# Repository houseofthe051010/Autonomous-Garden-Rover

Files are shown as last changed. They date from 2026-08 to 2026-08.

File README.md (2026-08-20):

# Autonomous Garden Rover

This is an open source outdoor garden robot that can mow grass and water plants for under $400. It features a powerful 3000 watt C6374 motor for mowing grass with electronic height control, and a large Nema17 turret system for watering at target places that supports a normal garden hose. The rover currently uses a 9 axis IMU + wheel encoders for autonomous function. The brain of this rover is a powerful ESP32-P4, which gives this rover the capability to listen and respond to commands using its built in microphone and speaker. 

## Inspiration

I spend hours each week gardening and mowing grass. As someone into robotics, I realized I could build a garden rover to automate some of these repetitive chores. This project gave me a reason to learn more about robotics while building something useful for my yard.

[**Watch the demo**](https://youtu.be/P-olpegfmmU) · [**Macondo journal**](https://macondo.hackclub.com/projects/9276) · [**See the assembly**](CAD/)

Autonomous Garden Rover demo (https://youtu.be/P-olpegfmmU)

## Features

* Under $400, anyone can build it
* All four wheels are motorized
* C6374 Motor offers 3000W+ of power, more than most commercial systems
* Nema17 planetary motors lift and raise the mower using a rope system.
* The turret system uses high reduction worm + dual stage planetary drives to shoot water
* Has a microphone and speaker and can run small ai vision/text recognition models
* Water flow can be controlled using a seperate esp32 controller
* Can be controlled from a phone or handheld controller
* Uses a 9axis imu and encoders on all four wheels for precise autonomous
* The aluminum chassis bends and acts as a suspension
* Supports raspberry pi 5 with ROS 2 as brain
* Supports a custom hand held controller from my previous FPV claw drone project
* Advanced flexibility for conneting new sensors, cameras, and electronics
* Water resistant

# Building it yourself

Go to [**INSTRUCTIONS.md**](INSTRUCTIONS.md) to see the complete build instructions.

## Block schematic

This is a block level schematic of how each system is split

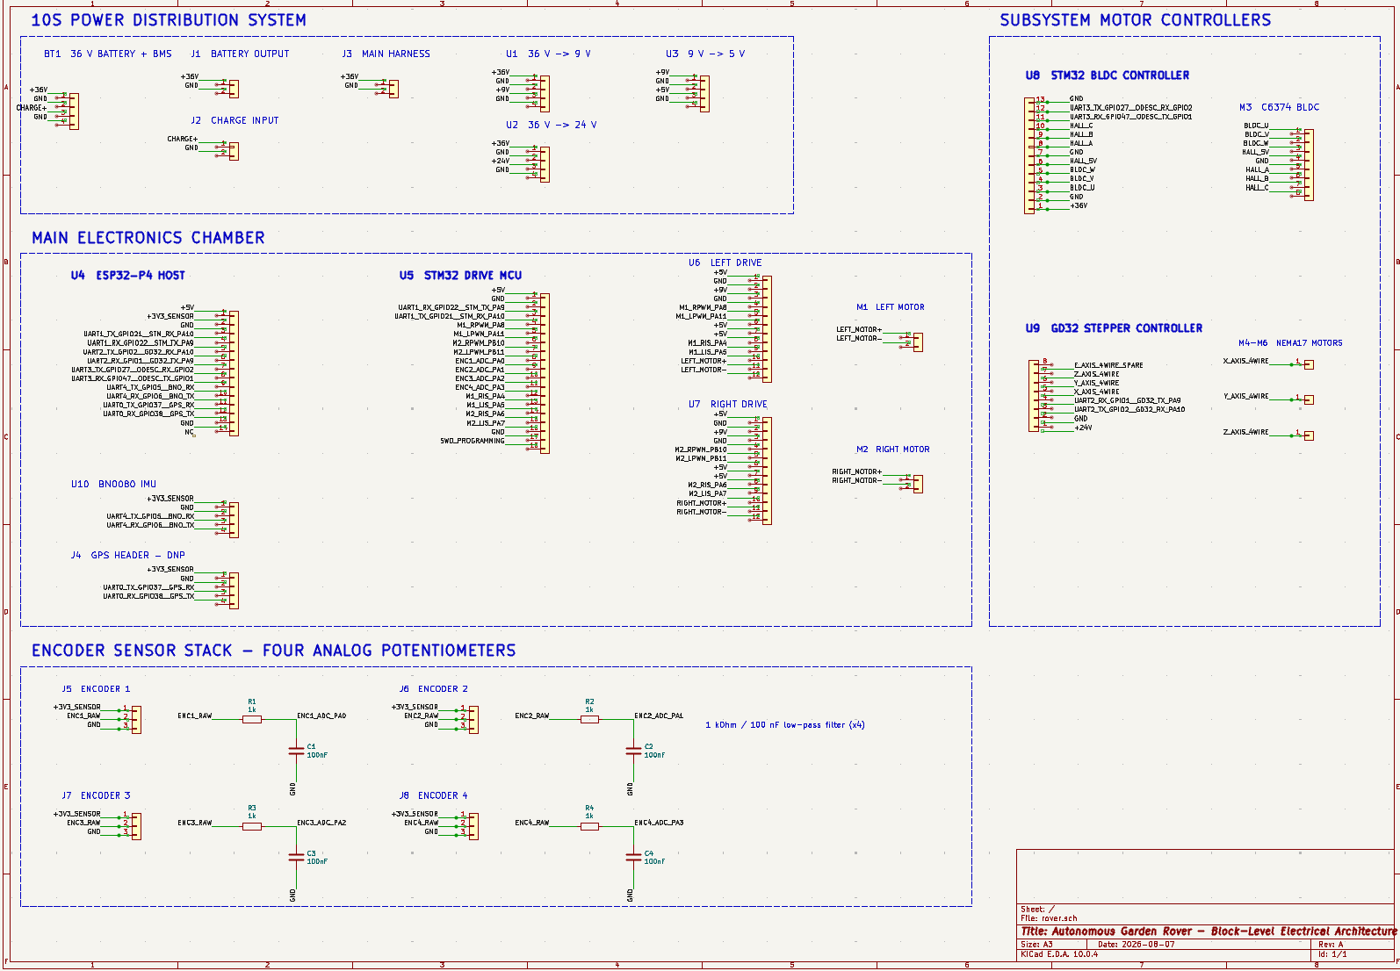
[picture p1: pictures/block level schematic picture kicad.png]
Block-level electrical schematic


Kicad: [`Schematics/Block-level schematic/`](Schematics/Block-level%20schematic/).

## Bill of materials

| Item | Qty. | Unit price | Total | Link |
| --- | ---: | ---: | ---: | --- |
| Waveshare ESP32-P4-WIFI6 development board | 1 | $26.87 | $26.87 | [Amazon](https://www.amazon.com/dp/B0FM3SPXZG) |
| Steelworks 3/4 in x 8 ft aluminum channel | 2 | $19.98 | $39.96 | [Lowe's](https://www.lowes.com/pd/Steelworks-3-4-in-W-x-8-ft-L-Mill-Finished-Aluminum-Weldable-Trim-Channel/3058185) |
| LGXSHOP C6374 170KV sensored BLDC motor | 1 | $29.50 | $29.50 | [Amazon](https://www.amazon.com/dp/B0GR88K1XP) |
| STM32F103C6T6 Blue Pill development board | 1 | $1.75 | $1.75 | [AliExpress](https://www.aliexpress.us/item/3256809531654480.html) |
| BTS7960 high-current motor driver board | 2 | $5.56 | $11.12 | [AliExpress](https://www.aliexpress.us/item/3256812145540065.html) |
| DS3230 PRO drivetrain servo motors (4-pack) | 1 | $41.37 | $41.37 | [AliExpress](https://www.aliexpress.us/item/3256808314550897.html) |
| STEPPERONLINE NEMA 17 stepper motors (3-pack) | 1 | $25.99 | $25.99 | [Amazon](https://www.amazon.com/dp/B0B38GHRH8) |
| Stepper controller board (12-24 VDC) | 1 | $22.99 | $22.99 | [Amazon](https://www.amazon.com/dp/B0CCVSMGXR) |
| EONO PETG 3D printer filament 1 kg black | 2 | $9.99 | $19.98 | [Amazon](https://www.amazon.com/EONO3D-Printer-Filament-1-75mm-2-2lbs/dp/B0G2BQQ5RT) |
| 608 sealed steel bearings (20-pack) | 1 | $4.99 | $4.99 | [Amazon](https://www.amazon.com/dp/B0GX14YCFF) |
| M3 screw kit (420-piece) | 1 | $8.98 | $8.98 | [Amazon](https://www.amazon.com/dp/B0CSWD34KJ) |
| Flipsky ODESC 56 V v4.2 single-axis controller | 1 | $39.99 | $39.99 | [Amazon](https://www.amazon.com/dp/B0CB64MVHC) |
| 22 AWG wire (10 m) | 1 | $2.81 | $2.81 | [AliExpress](https://www.aliexpress.us/item/3256801511977665.html) |
| 36 V 10.4 Ah lithium battery with charger and XT60 connector | 1 | $79.99 | $79.99 | [eBay](https://www.ebay.com/itm/318206384216) |
| 20 A buck converter | 2 | $3.58 | $7.16 | [AliExpress](https://www.aliexpress.us/item/3256808333733098.html) |
| XL4005 buck converter | 1 | $1.99 | $1.99 | [AliExpress](https://www.aliexpress.us/item/3256808679872256.html) |
| MG996 servo motor | 1 | $3.44 | $3.44 | [AliExpress](https://www.aliexpress.us/item/3256802804659030.html) |
| ESP32-WROOM-32 development board with U.FL | 1 | $7.32 | $7.32 | [AliExpress](https://www.aliexpress.us/item/3256807142919728.html) |
| BNO080/BNO085 9-DOF sensor module | 1 | $18.99 | $18.99 | [Amazon](https://www.amazon.com/dp/B0HCBRBZ76) |
| Hello Hobby 3/8 in x 36 in wood dowel | 1 | $0.78 | $0.78 | [Walmart](https://www.walmart.com/ip/684374236) |
| Tool Bench 40 ft diamond-braid rope with winder | 1 | $1.50 | $1.50 | [Dollar Tree](https://www.dollartree.com/tool-bench-40-ft-diamond-braid-rope-with-winder-1-ct/295406) |
| **Estimated total** | | | **$397.47** | |

## What I would do differently next time and plan for in the future

- Add cameras and GPS+RTK to the autonomous sensors
- Use stronger drivetrain motors to support a higher speed and better turning (though it would increase the price to build)
- Replace garden hose adapter system with a water tank onboard the rover
- Make a custom PCB that combines all the electronics and sub systems into one board with quick connectors for peripherals (much more expensive though)

## Repository Structure

In this repo, I have included everything needed to replicate and modify this project

- Firmware images and source code
- CAD source, assemblies, steps, and STLs
- Visual instruction manual
- Electrical schematics

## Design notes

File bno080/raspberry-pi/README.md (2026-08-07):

# Raspberry Pi 5 BNO080 UART-SHTP Client

This client reads fused and raw BNO080 data through Pi 5 UART4. It is normal
Python 3 code for Raspberry Pi OS and Thonny, not MicroPython.

The UART-SHTP round trip and fused sensor-report path were hardware-validated on
2026-07-22. See [`VALIDATED_WORKING_MODEL.md`](VALIDATED_WORKING_MODEL.md) for
the observed output, exact wiring, and remaining calibration work.

## Wiring

| Raspberry Pi 5 | Physical pin | BNO080 |
| --- | ---: | --- |
| GPIO12 / UART4 TX | 32 | RX, sometimes labelled SCL/RX |
| GPIO13 / UART4 RX | 33 | TX, sometimes labelled SDA/TX |
| GPIO22 | 15 | H_INTN, optional but recommended |
| GPIO23 | 16 | NRST, optional for the first test |
| GND | Any GND | GND |

UART signals are 3.3 V. Set UART-SHTP mode before sensor reset or power-up:

```text
PS1 = HIGH
PS0 = LOW
```

Breakout-board power inputs differ. Do not connect its power pin until the exact
module documentation confirms whether the pin expects regulated 3.3 V or a
higher `VIN`. A bare BNO080 uses 3.3 V-class power and logic.

## Enable UART4

Under `[all]` in `/boot/firmware/config.txt`:

```ini
dtoverlay=uart4-pi5
```

Save, reboot, and verify:

```sh
ls -l /dev/ttyAMA4
pinctrl get 12-13
```

Expected pin functions are UART4 TX on GPIO12 and UART4 RX on GPIO13.

## Python dependency

The client is standalone except for `pyserial`, which is already used by the
working STM32 client. Install it from Raspberry Pi OS if needed:

```sh
sudo apt update
sudo apt install python3-serial
```

In Thonny, use the same regular Python 3 interpreter as the validated STM32
motor client. Paste or open and run [`bno080_uart.py`](bno080_uart.py). No
virtual environment, Adafruit package, `board`, or `busio` module is required.

## Connection result

Before initializing sensor reports, the program performs an SHTP Buffer Status
Query/Notification round trip. A correct connection prints:

```text
BNO080 UART opened: /dev/ttyAMA4 at 3000000 baud (Pi TX GPIO12, RX GPIO13)
BNO080 UART-SHTP ROUND TRIP VERIFIED: buffer=... bytes
BNO080 SHTP reset complete
BNO080 initialized; fused navigation reports received
BNO080 dynamic accel/gyro/magnetometer calibration started
```

The executable-channel reset makes repeated Thonny runs reliable while the
BNO080 remains powered. Without it, the host's channel sequence counters restart
at zero but the sensor can retain its previous SHTP state and ignore new Set
Feature commands even though Buffer Status Query still responds.

If this round trip fails, check crossed TX/RX, common ground, UART-SHTP mode,
sensor power, and `/dev/ttyAMA4`. Do not randomly change the baud rate:
UART-SHTP is fixed at 3,000,000 baud, 8N1.

## Thonny shell

Print one fused sample:

```python
print_sample()
```

Read only the calibrated magnetometer vector `(x, y, z)` in microtesla:

```python
magnetometer()
print_magnetometer()
stream_magnetometer(5, 10)
```

The last command prints magnetometer, fused magnetic heading, and accuracy at
5 Hz for ten seconds. Use `stream_magnetometer(5)` to continue until Ctrl+C.

Print fused heading and vectors at 5 Hz for ten seconds:

```python
stream(5, 10)
```

Stream until Ctrl+C:

```python
stream(5)
```

Enable and display raw sensor ADC values for calibration logging:

```python
enable_raw_reports()
print_raw()
stream_raw(5, 10)
```

Check the accuracy field from the calibrated magnetometer report:

```python
calibration_status()
```

The client starts dynamic calibration automatically. With the sensor mounted in
its intended orientation and the drive motors stopped, slowly rotate the robot
or sensor through multiple headings and tilt it through different orientations.
Repeat until `calibration_status()` reaches `2` or preferably `3`. Keep the
sensor away from steel, magnets, motor power cables, speakers, and high-current
wiring while calibrating. Call `begin_calibration()` to restart the process.

An accuracy value of `0` is the sensor's own `unreliable` status, not a Python
placeholder. It is normal before calibration, but persistent zero can indicate
strong magnetic interference or insufficient movement through different axes.

This standalone subset does not write calibration records. That is intentional
for the first hardware test; it avoids changing persistent sensor state.

## Data provided

- Magnetic-north heading derived from the 9-axis rotation-vector quaternion.
- Rotation-vector quaternion `(i, j, k, real)`.
- Calibrated magnetic field in microtesla.
- Calibrated gyro in radians per second.
- Acceleration and gravity-removed linear acceleration in m/s^2.
- Optional raw accelerometer, gyroscope, and magnetometer ADC values.

The embedded driver implements the framing, buffer handshake, Set Feature
commands, and selected report formats from CEVA's binary
[UART-SHTP protocol](https://www.ceva-ip.com/wp-content/uploads/Sensor-Hub-Transport-Protocol.pdf)
and [SH-2 reference](https://www.ceva-ip.com/wp-content/uploads/SH-2-Reference-Manual.pdf).

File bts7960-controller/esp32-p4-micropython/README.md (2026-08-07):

# ESP32-P4 MicroPython STM32 UART Test

[`main.py`](main.py) is a standalone Thonny client for checking the existing
STM32F103 dual-BTS7960 firmware from an ESP32-P4.

## Wiring

The script tests both possible orientations automatically:

| Preferred connection | Direction |
| --- | --- |
| ESP32-P4 GPIO22 | TX to STM32 PA10 / USART1 RX |
| ESP32-P4 GPIO21 | RX from STM32 PA9 / USART1 TX |
| ESP32-P4 GND | STM32 GND |

If GPIO21 and GPIO22 are reversed, the script detects the STM32 heartbeat and
reconfigures UART1 to the reversed orientation. Both devices use 3.3 V UART
logic at 115200 baud, 8N1.

## Thonny

Use a current ESP32-P4 MicroPython build. Save the complete script to the
ESP32-P4 as `main.py`, then reset the board. A working link prints:

```text
received HB ...
UART round trip verified: OK PONG
STM32 CONNECTED: ...
```

Useful shell commands:

```python
ping()
check_connection()
motor_status()
currents()
monitor(5)
diagnostics()
stop_all()
```

`ping()` must return `OK PONG`. A heartbeat alone verifies only the
STM32-to-ESP32 direction; the PING/PONG exchange verifies both directions.
No background thread is started, so the Thonny shell remains usable.

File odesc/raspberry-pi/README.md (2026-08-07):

# Raspberry Pi 5 ODESC UART Client

This directory contains the regular Python 3/Thonny client for the rover's
ODESC (ODrive v3-compatible) motor controller. The bidirectional UART link was
hardware-validated on 2026-07-22. See
[`VALIDATED_WORKING_MODEL.md`](VALIDATED_WORKING_MODEL.md) for the observed
results.

## Wiring

| Raspberry Pi 5 | Physical pin | ODESC | Direction |
| --- | ---: | --- | --- |
| GPIO4 / UART2 TX | 7 | GPIO2 / UART RX | Pi to ODESC |
| GPIO5 / UART2 RX | 29 | GPIO1 / UART TX | ODESC to Pi |
| GND | Any Pi GND | GND | Common reference |

TX and RX must cross. Both devices use 3.3 V UART logic; do not put 5 V on a
UART signal. Power the ODESC from its intended motor power supply and connect
the grounds.

## Raspberry Pi setup

Add this under `[all]` in `/boot/firmware/config.txt`:

```ini
dtoverlay=uart2-pi5
```

Reboot, then verify:

```sh
ls -l /dev/ttyAMA2
pinctrl get 4-5
```

Install the only Python dependency:

```sh
sudo apt update
sudo apt install python3-serial
```

## Run the test

Open [`odesc_uart.py`](odesc_uart.py) in Thonny using its regular local Python 3
interpreter and run it. A successful result includes:

```text
ODESC UART ROUND TRIP VERIFIED
Bus voltage: 35.653049 V
UART enabled=1 baud=115200 | axis1 state=1 error=0
```

The voltage is only an example from the validation run and will follow the
connected motor supply. State `1` means idle. The firmware sometimes formats a
zero integer as `0d`; the client handles that representation.

## Robot API use

The client can be imported without performing I/O automatically:

```python
from odesc_uart import ODESCUART

odesc = ODESCUART()
odesc.open()
status = odesc.check_connection()
voltage = odesc.read_float("vbus_voltage")
odesc.close()
```

`query()` serializes access with a lock, validates one-line commands, and
applies a bounded timeout. The combined rover service keeps one `ODESCUART`
instance open so no other process may own `/dev/ttyAMA2`.

The client now provides:

- `telemetry()` for `vbus_voltage`, `ibus`, bus watts, and both axis snapshots.
- Per-axis position, velocity, measured/setpoint Iq, limits, calibration flags,
  state, component errors, sensorless-estimator velocity/error, motor pole
  pairs, flux linkage, and startup-ramp values.
- `configure_velocity_axis()` for volatile velocity mode and current/speed
  limits.
- `configure_sensorless_axis()` for legacy state-5 ramp settings expressed as
  mechanical turns/s and converted to electrical radians/s internally.
- `start_sensorless()`, `set_sensorless_velocity()`, and `stop_sensorless()`,
  including minimum-speed, fixed-direction, and IDLE-stop enforcement.
- `calibrate_motor()` for an encoderless axis that needs motor-only calibration.
- `clear_errors()` and guarded `calibrate_axis()`.
- Closed-loop state requests and signed velocity commands through the combined
  rover controller.

The deployed dashboard adds an 800 ms host-process velocity deadman, explicit
arm/calibration phrases, and persistent command/error records in
`~/rover-controller/rover-history.sqlite3`. Motor motion from the sensorless
controls has not yet been physically validated. The deadman cannot protect
against Pi power loss or every process failure; use an independent hardware
emergency stop.

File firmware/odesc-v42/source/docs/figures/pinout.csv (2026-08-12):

# | Label | GPIO_MODE_DIGITAL | GPIO_MODE_ANALOG_IN | GPIO_MODE_UART_A | GPIO_MODE_UART_B | GPIO_MODE_PWM | GPIO_MODE_CAN_A | GPIO_MODE_I2C_A | GPIO_MODE_ENC0 | GPIO_MODE_ENC1 | GPIO_MODE_MECH_BRAKE
0 | not a pin
1 | GPIO1 (+) | general purpose | analog input | **UART_A.TX** |  | PWM0.0 |  |  |  |  | mechanical brake
2 | GPIO2 (+) | general purpose | analog input | **UART_A.RX** |  | PWM0.1 |  |  |  |  | mechanical brake
3 | GPIO3 | general purpose | **analog input** |  | **UART_B.TX** | PWM0.2 |  |  |  |  | mechanical brake
4 | GPIO4 | general purpose | **analog input** |  | **UART_B.RX** | PWM0.3 |  |  |  |  | mechanical brake
5 | GPIO5 | general purpose | **analog input (*)** |  |  |  |  |  |  |  | mechanical brake
6 | GPIO6 (*) (+) | **general purpose** |  |  |  |  |  |  |  |  | mechanical brake
7 | GPIO7 (*) (+) | **general purpose** |  |  |  |  |  |  |  |  | mechanical brake
8 | GPIO8 (*) (+) | **general purpose** |  |  |  |  |  |  |  |  | mechanical brake
9 | M0.A | general purpose |  |  |  |  |  |  | **ENC0.A**
10 | M0.B | general purpose |  |  |  |  |  |  | **ENC0.B**
11 | M0.Z | **general purpose**
12 | M1.A | general purpose |  |  |  |  |  | I2C.SCL |  | **ENC1.A**
13 | M1.B | general purpose |  |  |  |  |  | I2C.SDA |  | **ENC1.B**
14 | M1.Z | **general purpose**
15 | not exposed | general purpose |  |  |  |  | **CAN_A.RX** | I2C.SCL
16 | not exposed | general purpose |  |  |  |  | **CAN_A.TX** | I2C.SDA

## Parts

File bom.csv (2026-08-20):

Item | Quantity | Unit Price (USD) | Total (USD) | Product Link
Waveshare ESP32-P4-WIFI6 development board | 1 | 26.87 | 26.87 | https://www.amazon.com/dp/B0FM3SPXZG
Steelworks 3/4 in x 8 ft aluminum channel | 2 | 19.98 | 39.96 | https://www.lowes.com/pd/Steelworks-3-4-in-W-x-8-ft-L-Mill-Finished-Aluminum-Weldable-Trim-Channel/3058185
LGXSHOP C6374 170KV sensored BLDC motor | 1 | 29.50 | 29.50 | https://www.amazon.com/dp/B0GR88K1XP
STM32F103C6T6 Blue Pill development board | 1 | 1.75 | 1.75 | https://www.aliexpress.us/item/3256809531654480.html
BTS7960 high-current motor driver board | 2 | 5.56 | 11.12 | https://www.aliexpress.us/item/3256812145540065.html
DS3230 PRO drivetrain servo motors (4-pack) | 1 | 41.37 | 41.37 | https://www.aliexpress.us/item/3256808314550897.html
STEPPERONLINE NEMA 17 stepper motors (3-pack) | 1 | 25.99 | 25.99 | https://www.amazon.com/dp/B0B38GHRH8
Stepper controller board (12-24 VDC) | 1 | 22.99 | 22.99 | https://www.amazon.com/dp/B0CCVSMGXR
EONO PETG 3D printer filament 1 kg black | 2 | 9.99 | 19.98 | https://www.amazon.com/EONO3D-Printer-Filament-1-75mm-2-2lbs/dp/B0G2BQQ5RT?sp_csd=d2lkZ2V0TmFtZT1zcF9hdGY
608 sealed steel bearings (20-pack) | 1 | 4.99 | 4.99 | https://www.amazon.com/Bearings-Premium-Steel-Sealed-Groove/dp/B0GX14YCFF
M3 screw kit (420-piece) | 1 | 8.98 | 8.98 | https://www.amazon.com/mxuteuk-420PCS-Screws-Socket-Wrench/dp/B0CSWD34KJ
Flipsky ODESC 56 V v4.2 single-axis controller | 1 | 39.99 | 39.99 | https://www.amazon.com/dp/B0CB64MVHC
22 AWG wire (10 m) | 1 | 2.81 | 2.81 | https://www.aliexpress.us/item/3256801511977665.html
36 V 10.4 Ah lithium battery with charger and XT60 connector | 1 | 79.99 | 79.99 | https://www.ebay.com/itm/318206384216
20 A buck converter | 2 | 3.58 | 7.16 | https://www.aliexpress.us/item/3256808333733098.html
XL4005 buck converter | 1 | 1.99 | 1.99 | https://www.aliexpress.us/item/3256808679872256.html
MG996 servo motor | 1 | 3.44 | 3.44 | https://www.aliexpress.us/item/3256802804659030.html
ESP32-WROOM-32 development board with U.FL | 1 | 7.32 | 7.32 | https://www.aliexpress.us/item/3256807142919728.html
BNO080/BNO085 9-DOF sensor module | 1 | 18.99 | 18.99 | https://www.amazon.com/dp/B0HCBRBZ76
Hello Hobby 3/8 in x 36 in wood dowel | 1 | 0.78 | 0.78 | https://www.walmart.com/ip/684374236
Tool Bench 40 ft diamond-braid rope with winder | 1 | 1.50 | 1.50 | https://www.dollartree.com/tool-bench-40-ft-diamond-braid-rope-with-winder-1-ct/295406
Estimated total |  |  | 397.47

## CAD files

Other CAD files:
CAD/Individual Printable STLs/motor blade attachment/mower main casing.stl
CAD/Sub-assemblies/motor blade attachment/Individual STEPs/mower main casing.step
CAD/Assembly/Individual STEPs/mower main casing.step
CAD/Assembly/mower body.step
CAD/Individual Printable STLs/electronics holders/main electronics holder/electronics holder bottom casing.stl
CAD/Individual Printable STLs/electronics holders/odrive holder v2/current odrive holder casing.stl
CAD/Individual Printable STLs/electronics holders/stepper controller holder/odrive bottom casing shell.stl
CAD/Individual Printable STLs/front and rear wheels/drivetrain motor holder.stl
CAD/Individual Printable STLs/hose turret/worm drive.stl
CAD/Individual Printable STLs/hose_control/casing mount rod.stl
CAD/Individual Printable STLs/motor blade attachment/string line mower attachment.stl
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

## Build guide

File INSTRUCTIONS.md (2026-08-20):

# Building it yourself

The complete development process is documented in my [Macondo journal](https://macondo.hackclub.com/projects/9276).
Below is a guide on how build the rover.

## System architecture

To replicate and built the rover, one should understand that there is one host computer, and many sub-system computers that control the whole rover. Each sub-system is linked using a UART channel to the host computer. This means that the host controller can be any computer you want, from a raspberry pi using ROS 2 to a esp32.

| Subsystem | Hardware | Purpose |
| --- | --- | --- |
| Main controller | ESP32-P4 + ESP32-C6 | Controls, AI processing and autonomous |
| Drivetrain | STM32F103  | Encoder feedback and drivetrain  |
| Stepper motion  | GD32F303 Ender-3 board  | Controls mower height and turret axes |
| Mower | STM32 oDrive clone | Controls the C6374 mowing motor |
| Pigeon | BNO080 | The 9 axis IMU |
| Hose valve | ESP32-WROOM-32 | Wireless faucet control |

### Why have many scattered subsystems?

I also designed a single-board host computer that combines the major electronics onto one PCB, with connectors for each peripheral. I haven't manufactured or tested it yet, as it is a option for people wanting to build this project to avoid the hassle of sub systems and communication links. The gerber files for the PCB is at:

[**Single-board host computer schematic and PCB files**](Schematics/Prototype%20single%20board%20host%20computer/)

The benefit with my current electronics layout is that it is significantly cheaper (helps keep the 400 dollar budget) and easier to repair, as the PCBs are already mass produced and working. Its like comparing a mini pc and a desktop pc, you can swap out parts in the desktop whenever you want. 

## Mechanical and electrical build

### 1. Print the parts

The printable files are grouped in [`CAD/Individual Printable STLs/`](CAD/Individual%20Printable%20STLs/).

#### Drivetrain

From [`front and rear wheels/`](CAD/Individual%20Printable%20STLs/front%20and%20rear%20wheels/):

- 4 × `mower wheel.stl`
- 4 × `motor spur gear.stl`
- 4 wheel output gears total: use the front and rear output-gear variants in their matching positions
- 6 drivetrain holders total: the CAD folder calls the two holder variants `drivetrain motor casing.stl` and `drivetrain motor holder.stl`; this guide refers to both as **drivetrain holders**

#### Mower head

From [`motor blade attachment/`](CAD/Individual%20Printable%20STLs/motor%20blade%20attachment/):

- `mower motor mount attachment.stl`
- `mower motor shaft attachment.stl`
- `mower main casing.stl`
- `mower motor casing.stl`
- `mower motor casing top.stl`
- `mower motor casing lid.stl`
- 4 × `blade arm.stl` or 4 × `string line mower attachment.stl`

#### Height control

Print the parts in [`mower height control system/`](CAD/Individual%20Printable%20STLs/mower%20height%20control%20system/) as they are called out in Section 4.

#### Structure and electronics

- [`aluminum channel mount.stl`](CAD/Individual%20Printable%20STLs/structural/aluminum%20channel%20mount.stl): 4 for the mower carriage, 2 for the main-electronics bridge, and 6 for the battery/turret rails
- 2 × [`battery holder perimeter part.stl`](CAD/Individual%20Printable%20STLs/structural/battery%20holder%20perimeter%20part.stl)
- Main enclosure: [`electronics holder bottom casing.stl`](CAD/Individual%20Printable%20STLs/electronics%20holders/main%20electronics%20holder/electronics%20holder%20bottom%20casing.stl), [`electronics holder top casing.stl`](CAD/Individual%20Printable%20STLs/electronics%20holders/main%20electronics%20holder/electronics%20holder%20top%20casing.stl), and [`wire management cover.stl`](CAD/Individual%20Printable%20STLs/electronics%20holders/main%20electronics%20holder/wire%20management%20cover.stl)
- ODESC enclosure: use the two files in [`odrive holder v2/`](CAD/Individual%20Printable%20STLs/electronics%20holders/odrive%20holder%20v2/)
- Stepper enclosure: use the two files in [`stepper controller holder/`](CAD/Individual%20Printable%20STLs/electronics%20holders/stepper%20controller%20holder/)

#### Hose turret and faucet controller

Use the files in [`hose turret/`](CAD/Individual%20Printable%20STLs/hose%20turret/) and [`hose_control/`](CAD/Individual%20Printable%20STLs/hose_control/) as named in Sections 6 and 7.

### 2. Cut and assemble the chassis

The complete cut list is:

| Use | Length | Quantity |
| --- | ---: | ---: |
| Main chassis cross rails | 420 | 3 |
| Main chassis side rails | 670 | 2 |
| Mower carriage side rails | 330 | 2 |
| Mower carriage crosspieces | 76 | 2 |
| Main-electronics supports | 150 | 2 |
| Battery and turret rails | 400 | 4 |
| ODESC/stepper support | 300 | 1 |

Lay out the 420 mm and 670 mm pieces as shown.

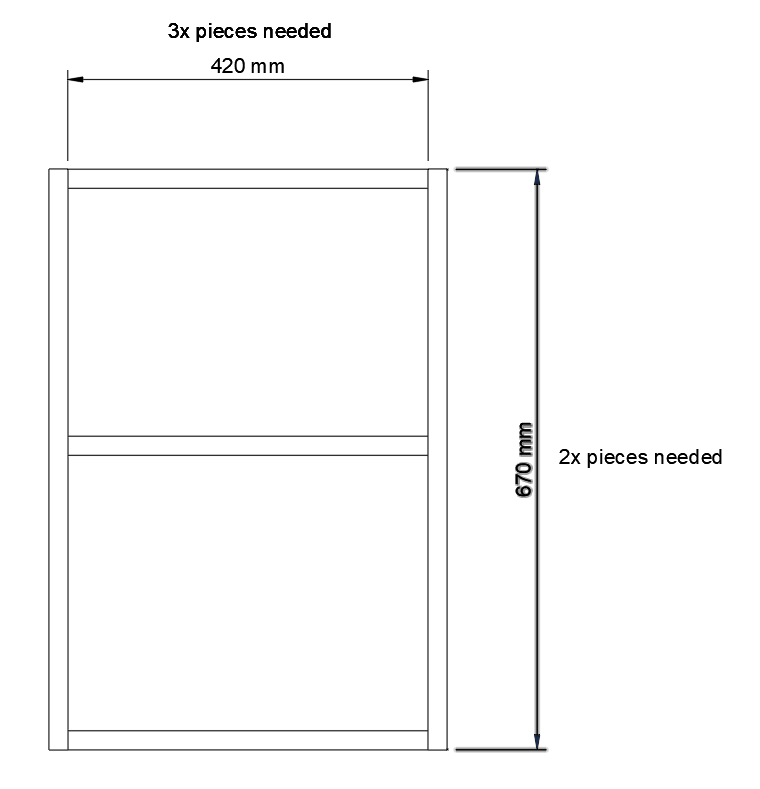
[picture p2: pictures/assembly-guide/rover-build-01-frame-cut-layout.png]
Main chassis cut layout


#### Build the four powered wheel modules

1. Open each DS3230 PRO servo and remove its control PCB.
2. Bring out five wires: two motor leads, potentiometer 3.3 V, potentiometer ground, and the potentiometer wiper.
3. Reassemble the servo and place it in a drivetrain holder.

<p align="center">
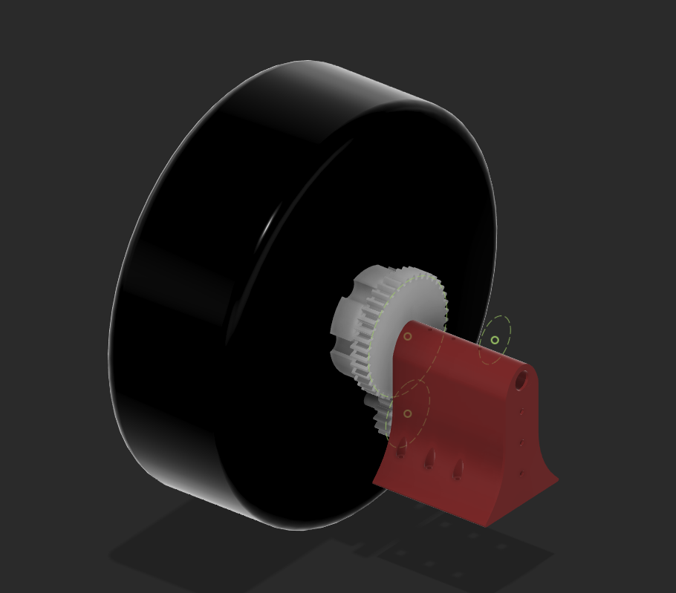
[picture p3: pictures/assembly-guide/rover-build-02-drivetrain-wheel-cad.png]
Complete drivetrain wheel CAD
  
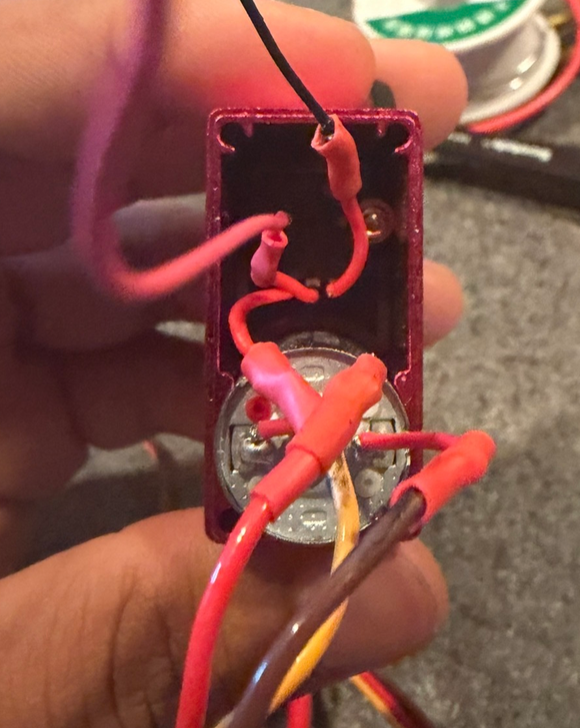
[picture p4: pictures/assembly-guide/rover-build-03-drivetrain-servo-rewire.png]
Opened drivetrain servo with motor and potentiometer wires
  
</p>

Attach `motor spur gear.stl` to the original servo horn with two M3 screws.

<p align="center">
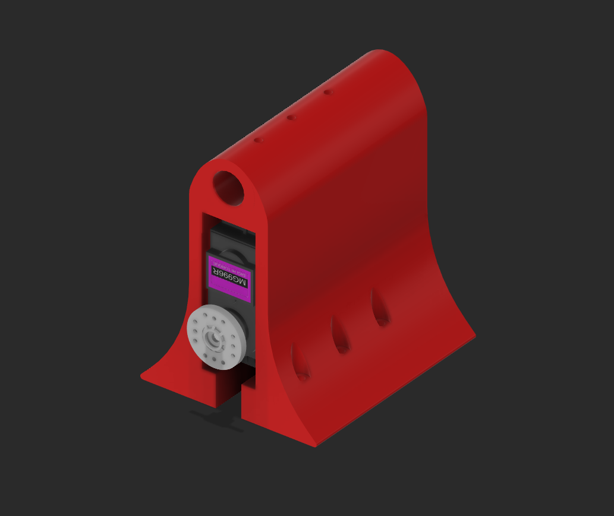
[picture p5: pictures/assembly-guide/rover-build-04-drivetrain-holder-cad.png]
Servo installed in drivetrain holder
  
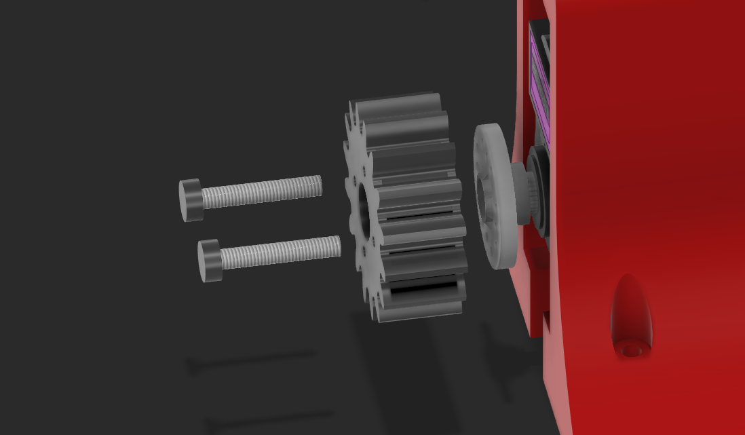
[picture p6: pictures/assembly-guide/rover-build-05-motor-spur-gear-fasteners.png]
Motor spur gear attached to servo horn
  
</p>

Push the wheel shaft through the matching output gear and wheel. Slide it through the holder, then lock it with an M3 screw in one of the three shaft slots.

<p align="center">
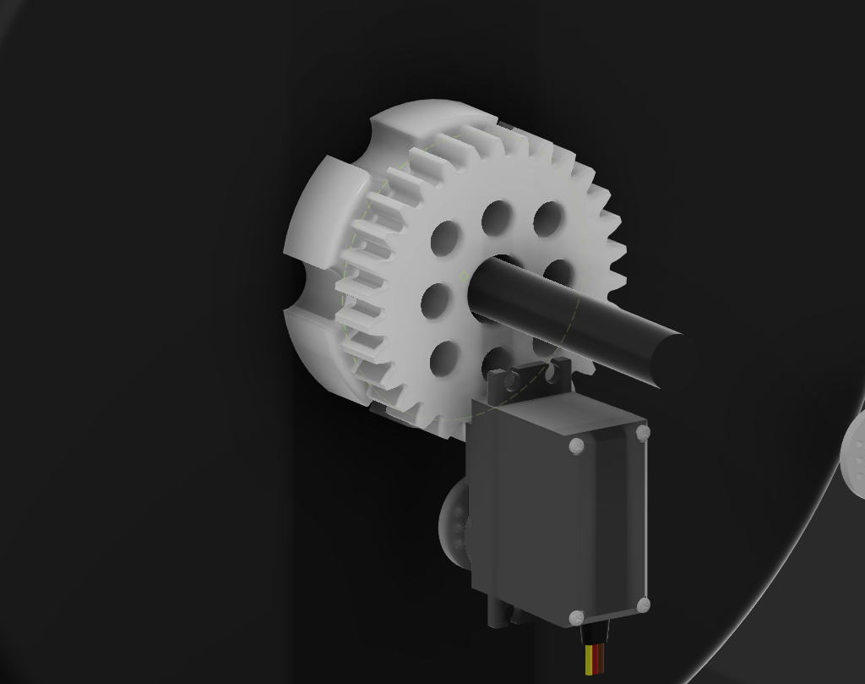
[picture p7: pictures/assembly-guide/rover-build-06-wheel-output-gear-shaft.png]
Wheel output gear and shaft
  
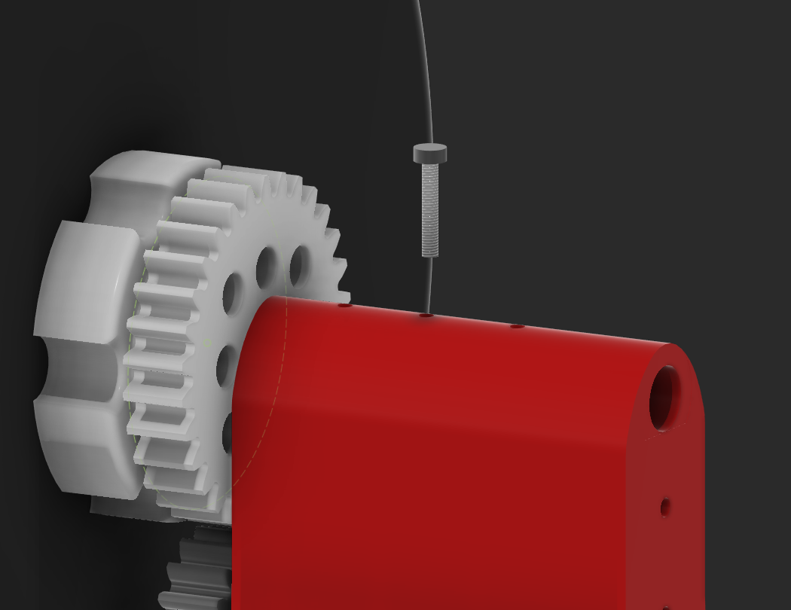
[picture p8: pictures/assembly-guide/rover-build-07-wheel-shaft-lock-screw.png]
M3 wheel shaft lock screw
  
</p>

Fit four powered holders at the corners and two unloaded holders at the center cross rail. Drill four M3 mounting holes at each corner and three at each center holder. Square the frame before tightening it.

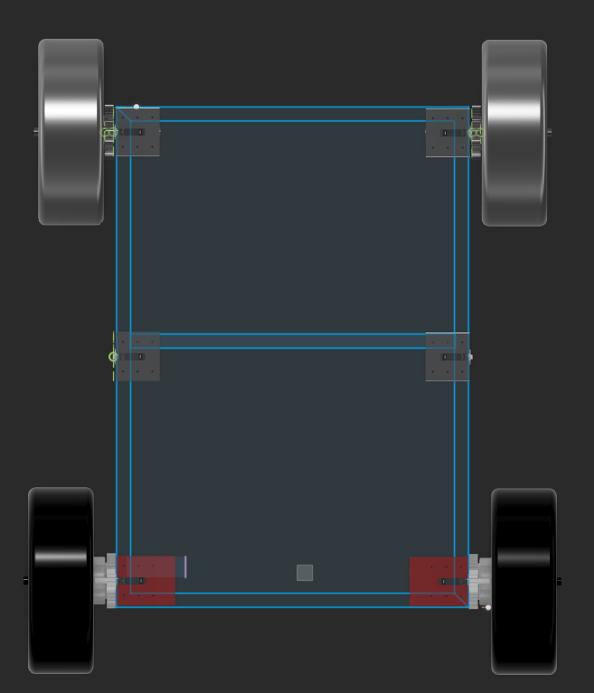
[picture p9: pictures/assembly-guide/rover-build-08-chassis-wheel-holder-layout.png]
Chassis and drivetrain-holder layout


### 3. Build the mower carriage and cutting head

Make the carriage from two 330 mm rails and two 76 mm crosspieces. Use four printed aluminum-channel mounts. The finished carriage is about 330 × 130 × 50 mm.

<p align="center">
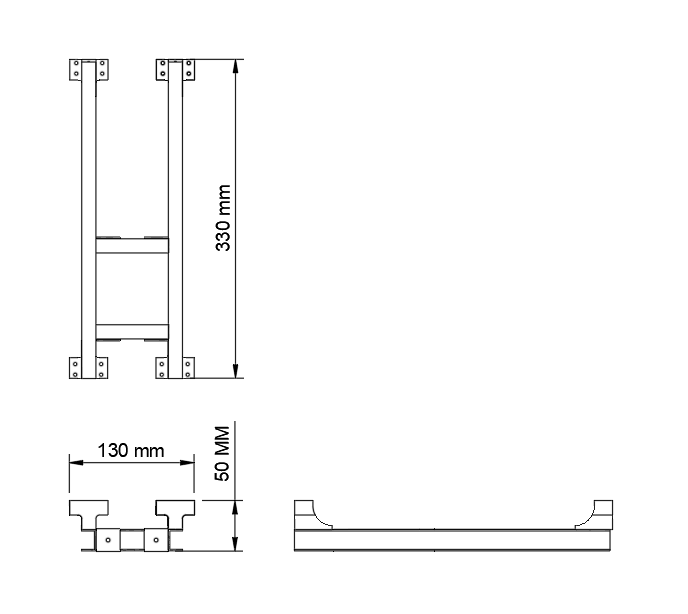
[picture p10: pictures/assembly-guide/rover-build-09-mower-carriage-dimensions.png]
Mower carriage dimensions
  
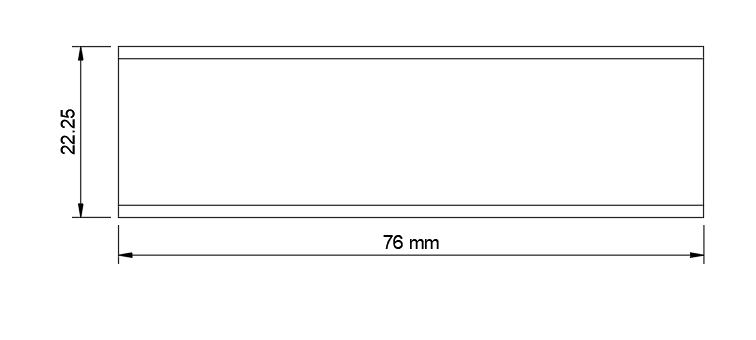
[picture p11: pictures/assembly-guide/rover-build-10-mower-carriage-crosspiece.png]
Mower carriage 76 mm crosspiece
  
</p>

Drill the main chassis and bolt the carriage across its center.

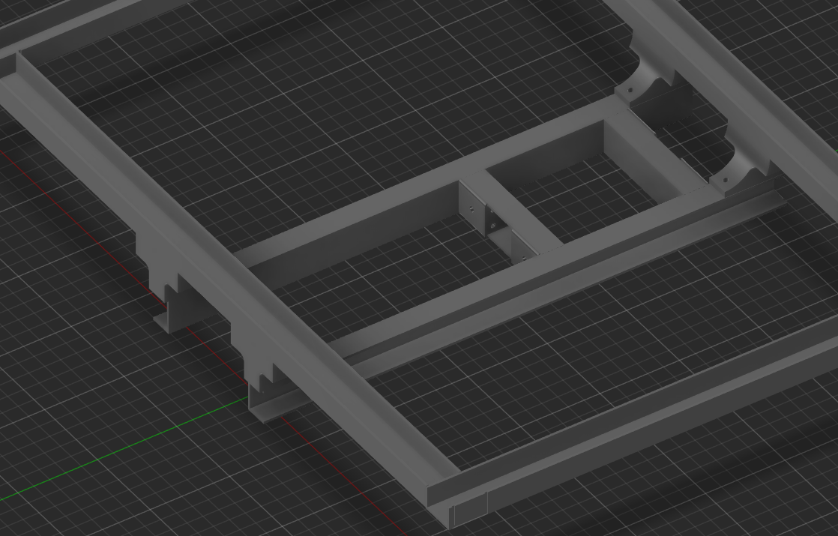
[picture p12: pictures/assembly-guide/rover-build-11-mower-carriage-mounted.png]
Mower carriage attached to chassis


1. Bolt `mower motor mount attachment.stl` to the C6374 using the four supplied M4 screws.
2. Press-fit `mower motor shaft attachment.stl` onto the motor shaft.
3. Attach `mower main casing.stl` with four 50 mm M3 screws.
4. Stack `mower motor casing.stl`, then glue on `mower motor casing top.stl`.
5. Keep `mower motor casing lid.stl` removable for service.

<p align="center">
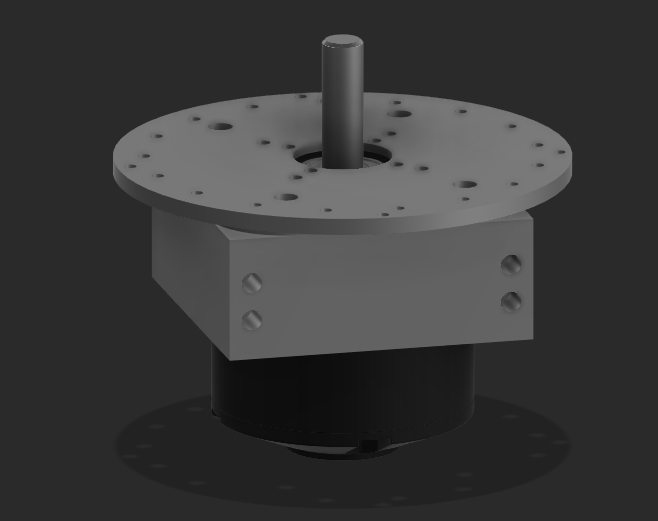
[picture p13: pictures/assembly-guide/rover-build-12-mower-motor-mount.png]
Mower motor mount
  
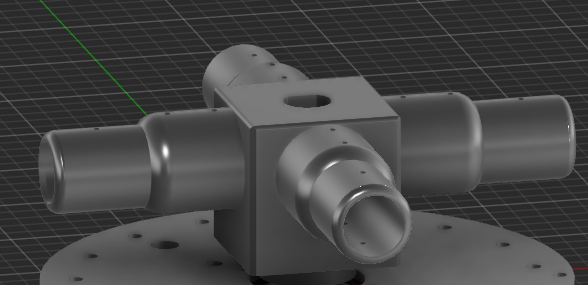
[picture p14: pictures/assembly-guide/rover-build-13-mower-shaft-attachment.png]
Mower shaft attachment
  
</p>

<p align="center">
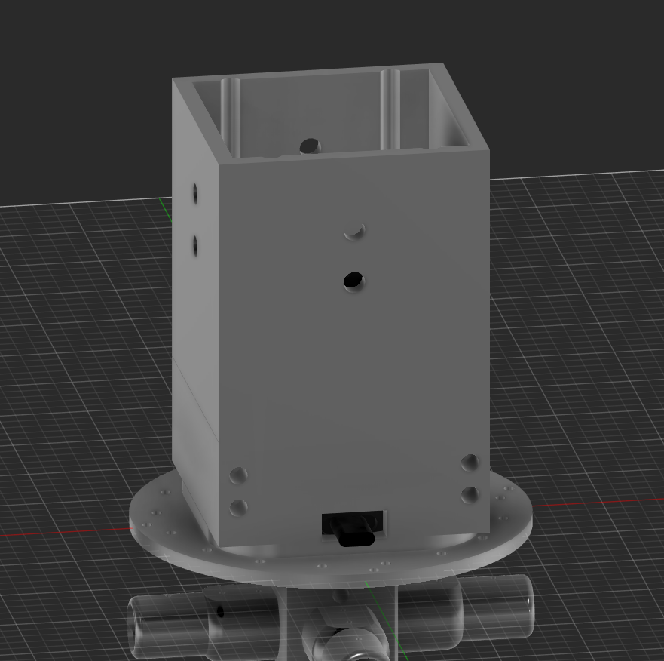
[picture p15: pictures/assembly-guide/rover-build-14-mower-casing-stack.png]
Mower casing stack
  
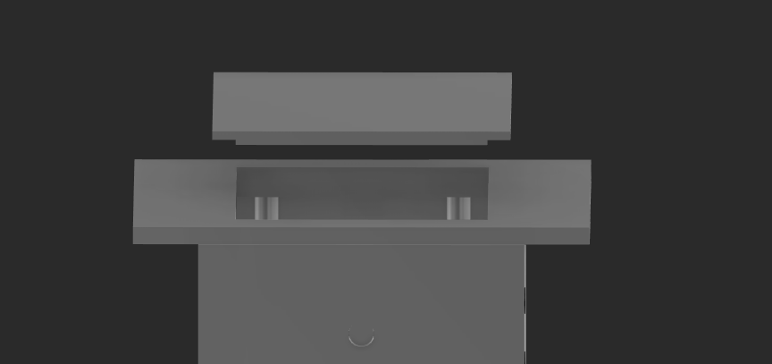
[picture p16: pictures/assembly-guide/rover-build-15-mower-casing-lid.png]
Mower casing lid
  
</p>

Attach four blade arms or four string-line holders to the shaft attachment with M3 screws. Leave the actual blades or line off until all electrical tests pass.

<p align="center">
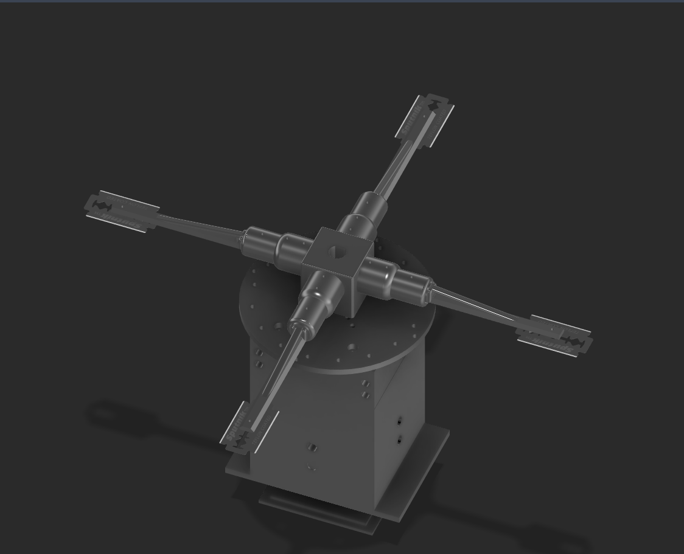
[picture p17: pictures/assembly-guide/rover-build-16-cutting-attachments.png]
Four mower cutting attachments
  
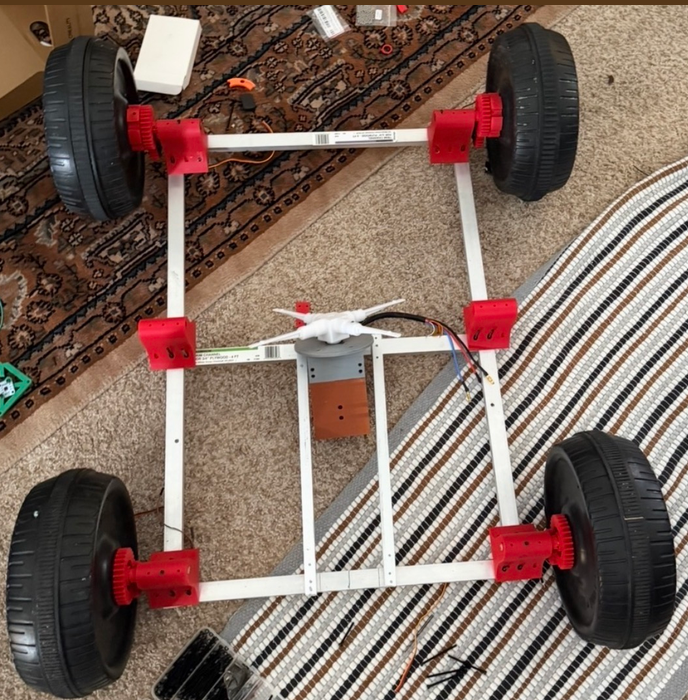
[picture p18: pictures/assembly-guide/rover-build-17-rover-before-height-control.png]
Rover before height-control installation
  
</p>

### 4. Build the mower height control

#### Assemble the gearbox and rope shafts

1. Print `height control base shell.stl` and `rope rod top stabilizer.stl`.
2. Mount the stabilizer using the rear NEMA 17 holes and longer 35 mm M3 screws.
3. Install two `rope output rod attachment.stl` parts with two 608 bearings per shaft.

<p align="center">
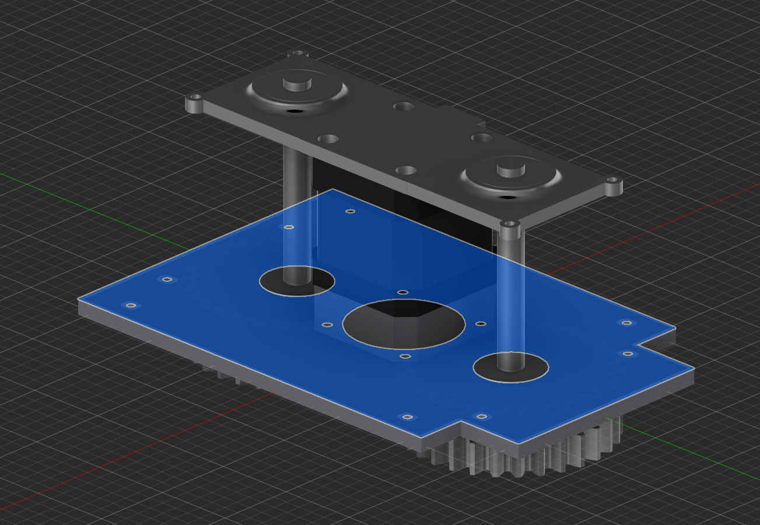
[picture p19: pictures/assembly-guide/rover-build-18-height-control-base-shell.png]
Height-control base shell
  
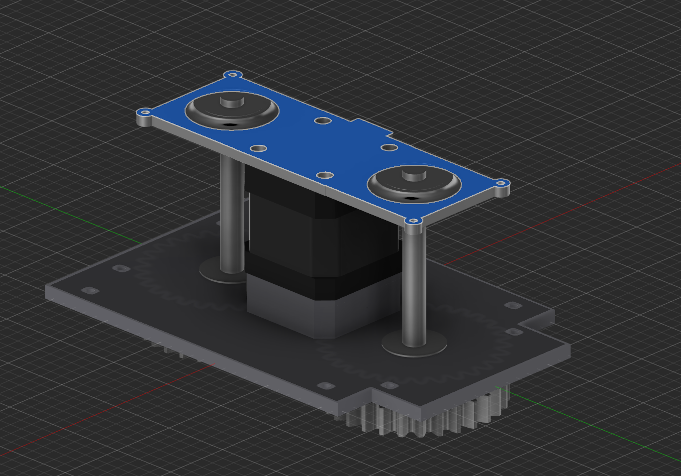
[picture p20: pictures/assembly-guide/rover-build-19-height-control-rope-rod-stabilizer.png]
Rope rod stabilizer
  
</p>

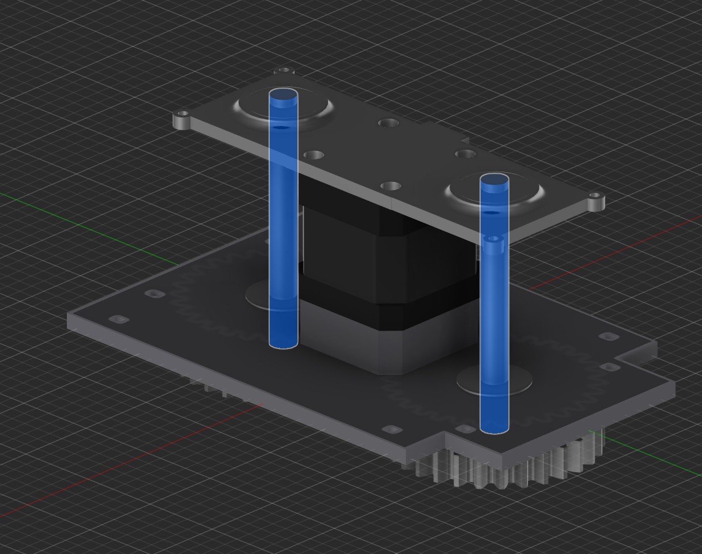
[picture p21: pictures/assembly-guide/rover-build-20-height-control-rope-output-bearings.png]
Rope output shafts and four bearings


Press `sun gear.stl` onto the NEMA 17 shaft. Fit the planet gears around it on `planetary output.stl`, then install the ring-gear casing and `height control base shell.stl`. Secure the stack with four 35 mm M3 screws.

<p align="center">
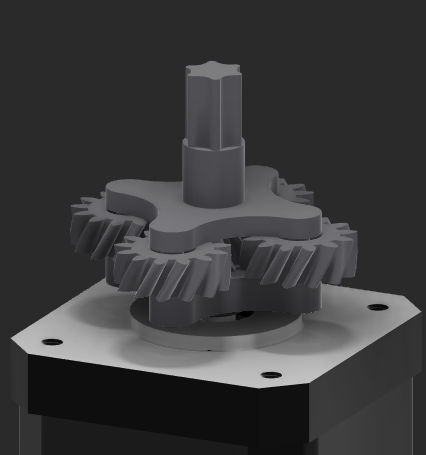
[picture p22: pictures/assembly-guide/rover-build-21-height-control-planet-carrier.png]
Height-control planet gears and carrier
  
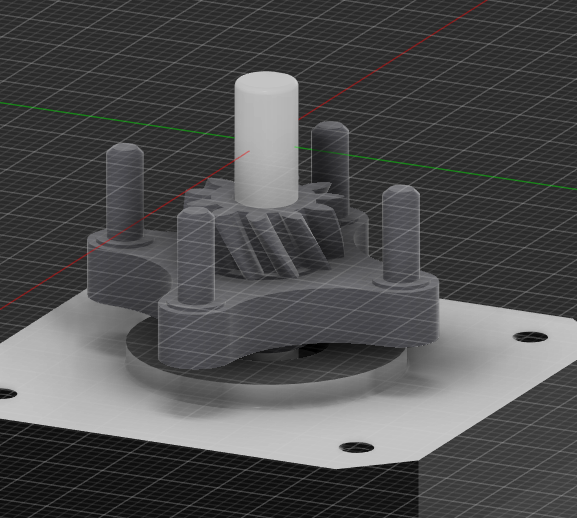
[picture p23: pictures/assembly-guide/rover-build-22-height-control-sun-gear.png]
Height-control sun gear
  
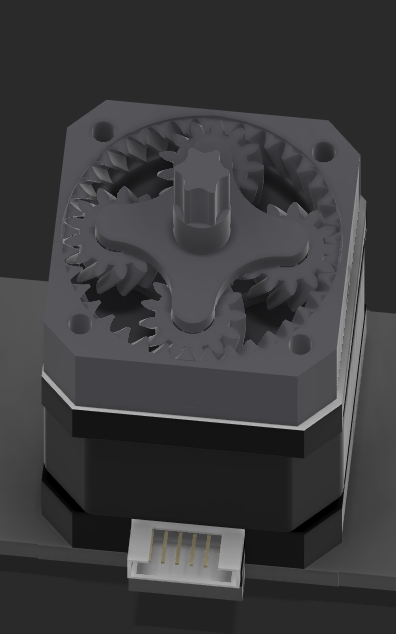
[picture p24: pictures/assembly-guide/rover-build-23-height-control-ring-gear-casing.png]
Height-control ring gear casing
  
</p>

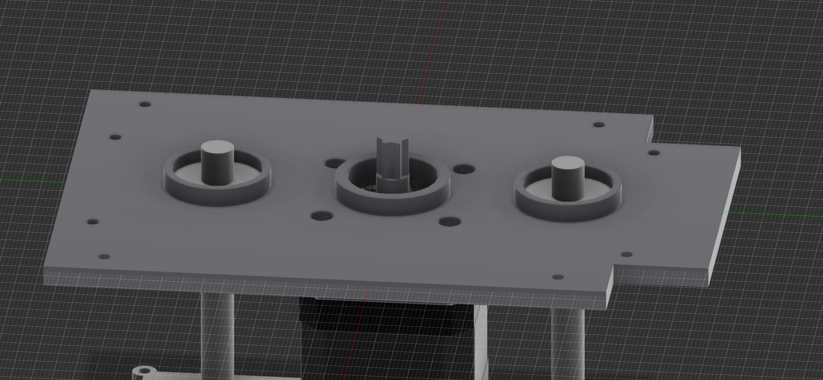
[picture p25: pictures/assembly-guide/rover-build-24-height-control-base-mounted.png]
Height-control base installed above gearbox


Bolt the module to the chassis with four M3 screws. Fit `nema17 planetary output gear.stl` in the center and one `output shaft rope rod gear.stl` on each side shaft. Drill and tap each shaft for an M3 locking screw.

<p align="center">
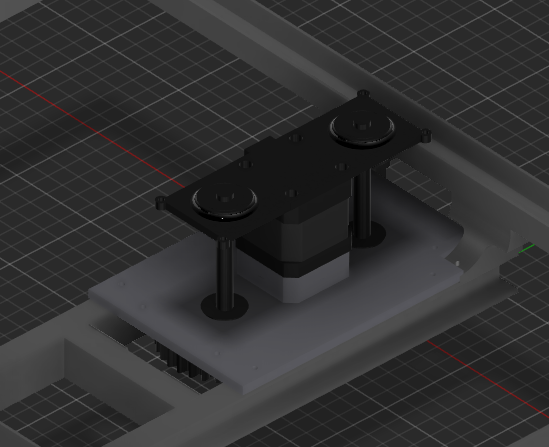
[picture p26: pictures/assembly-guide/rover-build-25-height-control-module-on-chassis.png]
Height-control module mounted on chassis
  
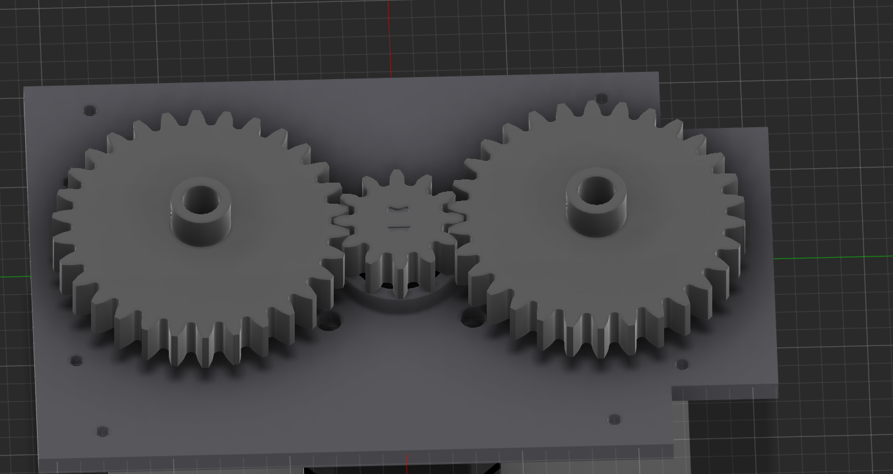
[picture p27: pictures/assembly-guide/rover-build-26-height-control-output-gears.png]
Height-control output gears
  
</p>

Fit the printed enclosure around the NEMA 17.

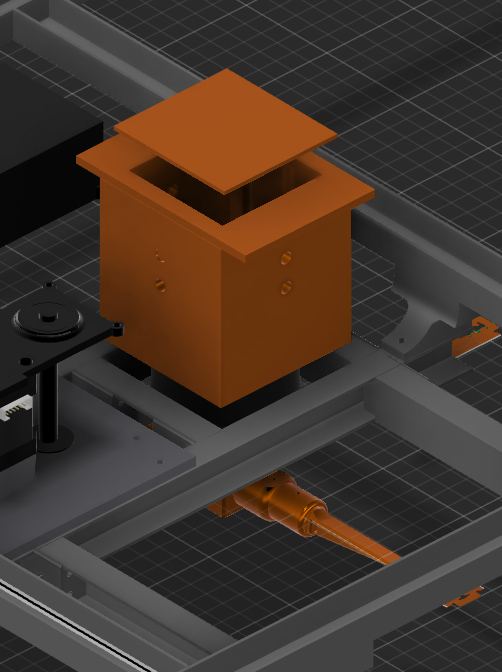
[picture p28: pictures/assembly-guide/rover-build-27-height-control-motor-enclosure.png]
Height-control motor enclosure


#### Route the lift ropes

Mount four `spacer.stl` rollers at R1–R4 and `rope tensioner.stl` at R5. Add `height control system rope blocker.stl` above the rollers so the rope cannot jump out.

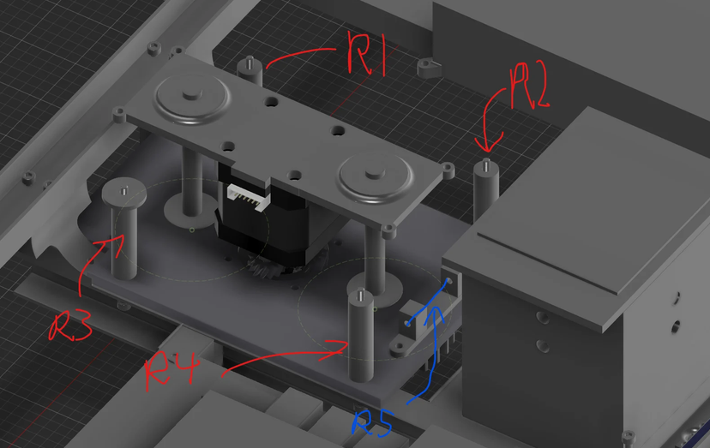
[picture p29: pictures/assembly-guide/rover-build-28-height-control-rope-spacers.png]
Height-control spacer and tensioner positions


Install `rope friction reducer.stl` guides in 8 mm holes along the rope path.

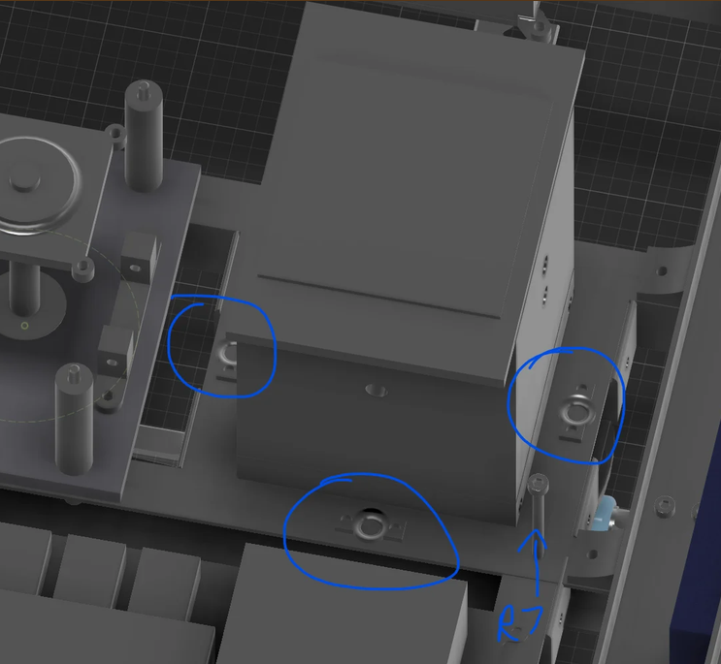
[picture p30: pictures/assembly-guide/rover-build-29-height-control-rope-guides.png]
Height-control rope guides


Anchor the ropes to the mower lid. Route them through the guides and rollers, then fasten them to the two winding shafts with M3 screws. Each shaft needs one rope run for lifting and one for lowering. Turn the system by hand and confirm that both sides remain level.

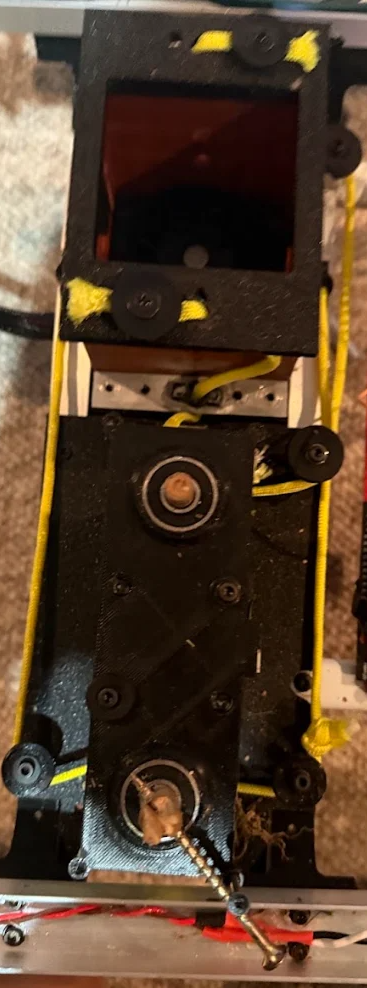
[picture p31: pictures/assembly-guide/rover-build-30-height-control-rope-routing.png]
Height-control rope routing


### 5. Mount the main enclosure and battery rails

The main enclosure uses exactly these three printed parts: bottom casing, top casing, and wire-management cover.

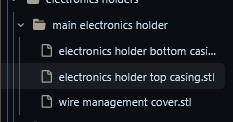
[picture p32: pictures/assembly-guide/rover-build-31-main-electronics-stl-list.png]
Main-electronics STL files


Cut two 150 mm channels. Mount them along the sides with two printed channel mounts and 50 mm M3 screws, then bolt the electronics enclosure across them with 25 mm M3 screws.

<p align="center">
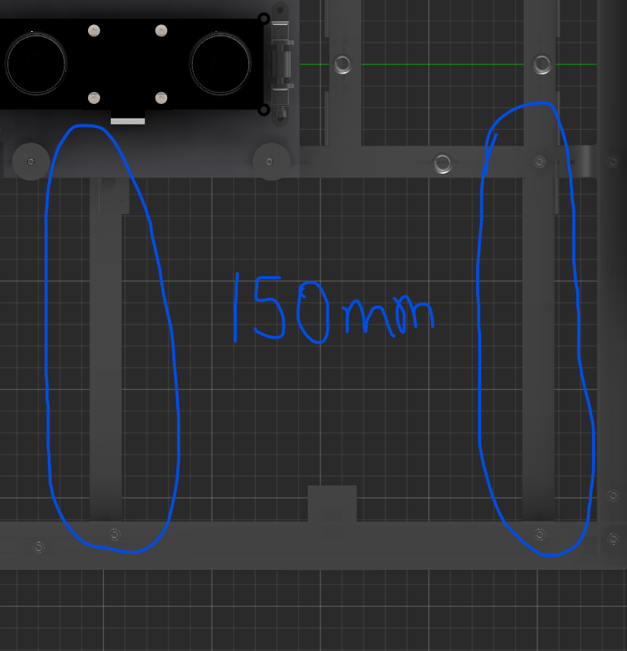
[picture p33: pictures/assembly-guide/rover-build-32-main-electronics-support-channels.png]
Main-electronics support channels
  
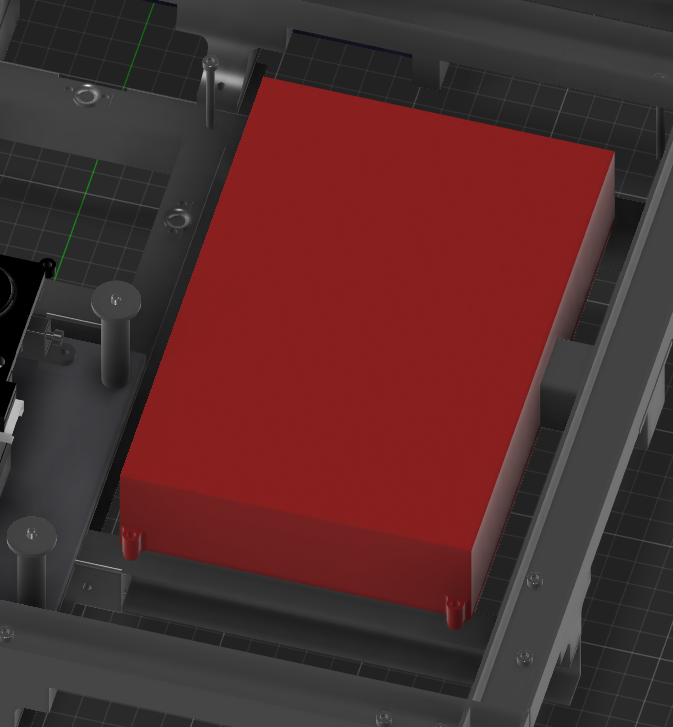
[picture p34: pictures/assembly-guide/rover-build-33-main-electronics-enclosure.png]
Main-electronics enclosure on support channels
  
</p>

Cut four 400 mm rails. Two support the battery and two support the hose turret. Use six printed channel mounts. Install the battery-retaining rail vertically, following the offsets in the figure.

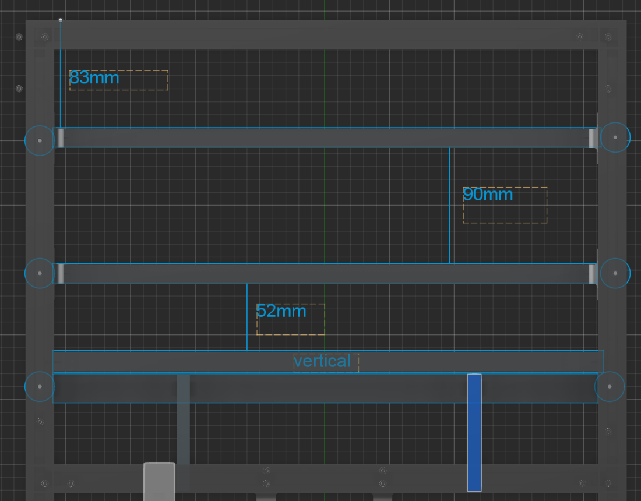
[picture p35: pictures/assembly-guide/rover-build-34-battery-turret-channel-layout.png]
Battery and turret rail layout


Fit two `battery holder perimeter part.stl` pieces 215 mm apart, then place the battery between the vertical retainers.

<p align="center">
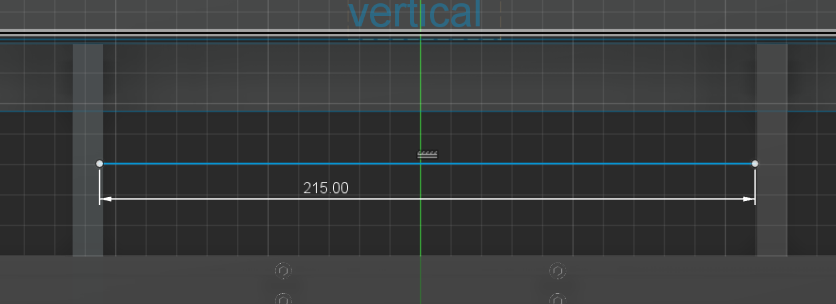
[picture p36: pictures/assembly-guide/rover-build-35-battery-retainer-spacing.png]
Battery retainer spacing
  
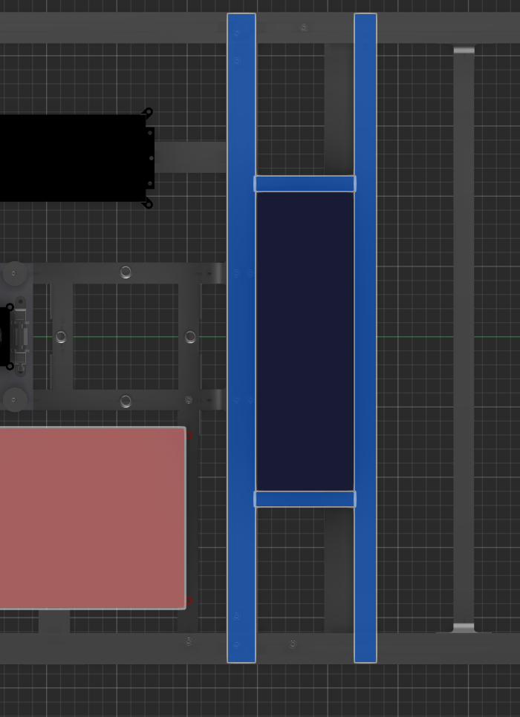
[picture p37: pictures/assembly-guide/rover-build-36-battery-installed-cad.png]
Battery installed between retaining rails
  
</p>

### 6. Build the hose turret

The completed yaw and pitch assembly should match this layout.

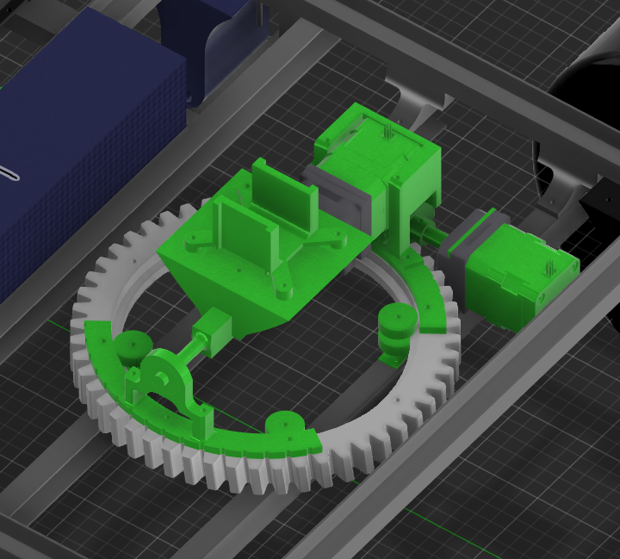
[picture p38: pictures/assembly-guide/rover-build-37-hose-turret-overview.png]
Complete hose turret CAD


#### Yaw axis

Mount four `turret wheel bearing rod.stl` parts with 50 mm M3 screws and locknuts. Check that both diagonals measure 148 mm so the rods are square.

<p align="center">
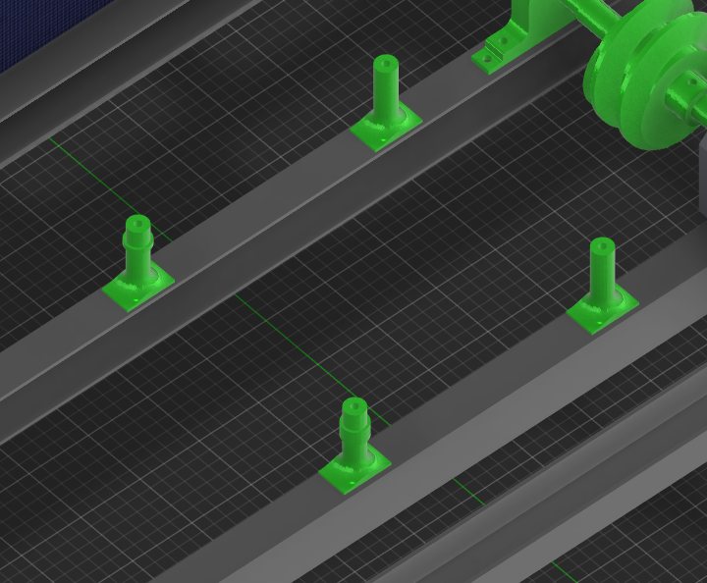
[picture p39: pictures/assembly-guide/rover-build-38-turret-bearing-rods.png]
Four turret bearing rods
  
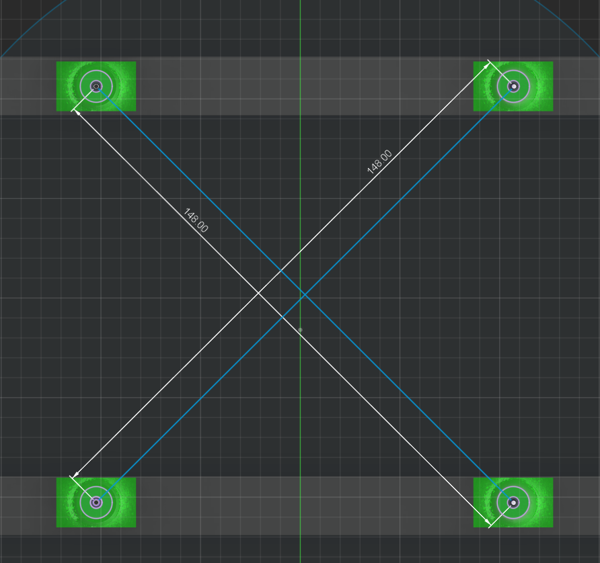
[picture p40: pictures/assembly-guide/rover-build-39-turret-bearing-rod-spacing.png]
Turret bearing rod diagonal spacing
  
</p>

Mount the yaw NEMA 17 and its planetary stage 67.5 mm from the corner rod. Use `turret yaw nema17 attachment.stl`, the gearbox support and casing, the sun gear, planet gears, and the first-stage output.

<p align="center">
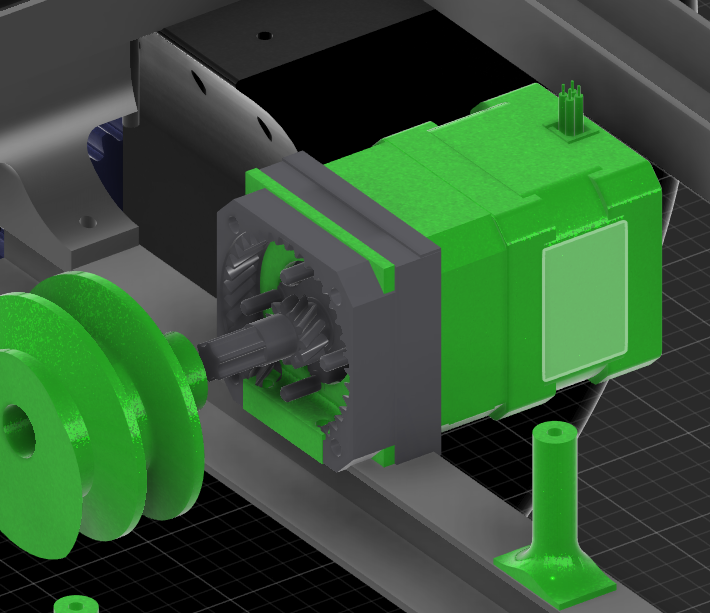
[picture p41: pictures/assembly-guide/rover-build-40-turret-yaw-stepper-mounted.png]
Yaw stepper mounted
  
  Yaw stepper 67.5 mm offset
</p>

Fit `worm drive.stl` to `worm drive rod.stl`. Support its far end with one 608 bearing in `turret yaw bearing holder.stl`, fastened with two 30 mm M3 screws.

Turret yaw worm drive

Install four 608 bearings on the rods, add `turret wheel bearing rod spacer.stl`, lower `worm wheel.stl` into place, then add four more bearings. Use washers under the M3 nuts so the bearings cannot lift off.

Worm wheel between eight bearings

#### Pitch axis

Bolt `turret pitch nema17 spacer.stl` to the worm wheel with 25 mm M3 screws. Mount `nema17 holder turret pitch.stl` 10 mm above the bottom edge.

<p align="center">
  Pitch stepper adapter on worm wheel
  Pitch NEMA 17 holder
</p>

On the opposite side, install `turret pitch bearing adapter.stl`, a 608 bearing, and `axis stabilizer bearing holder 608.stl` with 25 mm M3 screws.

Pitch-axis bearing adapter

Build the first planetary stage the same way as the height-control gearbox. For the second stage:

1. Fit `planetary 1st to 2nd stage coulper sun gear output holder.stl` to the first-stage output.
2. Add `planetary 2nd stage output shafts.stl` and the planet gears.
3. Close the stage with the matching `planteray 2nd stage output` part.
4. Attach `planetary output shaft axis stabilzier.stl` to the bearing side.

Dual-stage pitch gearbox

Insert the long pitch shaft into the axis stabilizer. Drill and tap an M3 hole about 10 mm deep to lock it. Fit `nema17 planetary output shaft extender.stl` at the top and lock it with two M3 screws about 50 mm from the top.

<p align="center">
  Pitch output shaft
  Pitch shaft extender
</p>

Bolt `hose attachment adapter.stl` to the pitch shaft assembly. Fit `hose pipe adapter.stl` inside it for a standard US garden hose.

<p align="center">
  Hose attachment adapter
  Garden hose pipe adapter
</p>

### 7. Build the wireless faucet controller

Press-fit or glue the MG996 servo into `casing bottom shell mg996 holder.stl`. Attach `hose faucet control adapter.stl` to the servo horn with tapped 5 mm M3 screws.

<p align="center">
  MG996 faucet servo mount
  Faucet adapter on servo horn
</p>

Convert the MG996 for continuous rotation while keeping its potentiometer as an external encoder:

- Disconnect the potentiometer from the servo controller and complete the normal centered-feedback continuous-rotation conversion.
- Connect the potentiometer outer terminals to ESP32 **3.3 V** and ground; connect the wiper to **GPIO35**.
- Connect the servo signal to **GPIO14**.
- Power the servo from a separate 5 V branch capable of its stall current. Join its ground to the ESP32 ground; do not pass servo current through the ESP32 regulator.

Install the ESP32-WROOM-32 inside `casing middle section.stl`, route the USB power cable through the opening, and mount the U.FL connector through `mount top lid casnig.stl`.

<p align="center">
  Hose controller electronics enclosure
  ESP32 and wiring inside faucet controller
</p>

Slide `casing mount rod.stl` through the enclosure into `mount output shaft holder.stl`. Install `external mount.stl` with two 608 bearings.

<p align="center">
  Faucet-controller casing mount rod
  External faucet-controller mount and bearings
</p>

Clamp the assembly beside the faucet and power it from a 5 V power bank or outdoor-rated supply.

Wireless faucet controller installed

### 8. Mount and wire the rover electronics

#### ODESC and stepper-controller enclosure

Cut one 300 mm channel and mount it on the front-right side. Bolt the ODESC V4.2 enclosure and stepper-controller enclosure to it with two screws per case.

<p align="center">
  ODESC and stepper support channel
  ODESC and stepper enclosures
</p>

Route the three NEMA 17 cables through the stepper case. Route the C6374 phase and sensor wires directly into the ODESC case.

ODESC and stepper-controller wiring

#### Power distribution

Use the [block-level KiCad schematic](Schematics/Block-level%20schematic/) as the connector reference.

Block-level electrical schematic

| Source | Destination |
| --- | --- |
| 36 V battery | ODESC V4.2 battery input |
| 36 V battery → 24 V converter | GD32 stepper board and three NEMA 17 motors |
| 36 V battery → 9 V converter | Both BTS7960 motor-power inputs |
| 9 V rail → 5 V XL4005 | ESP32-P4, STM32, BNO080, and BTS7960 logic |

All rails must share ground.

Solder two fused branches in parallel at the XT60 battery output: one for the ODESC and one for the buck converters/main electronics.

#### Drivetrain controller

Each BTS7960 drives the two motors on one side in parallel. Connect both enable pins to 5 V and use these STM32 signals:

| Side | RPWM | LPWM | R current sense | L current sense |
| --- | --- | --- | --- | --- |
| Left / M1 | PA8 | PA11 | PA4 | PA5 |
| Right / M2 | PB10 | PB11 | PA6 | PA7 |

Connect the four wheel potentiometer wipers to **PA0, PA1, PA2, and PA3**. For each input, use the schematic's 1 kΩ series resistor and 100 nF capacitor to ground. Power the potentiometers from the 3.3 V sensor rail, not 5 V. Label which wheel uses each ADC input.

#### Host UART wiring

Cross TX to RX and connect a common ground for every link.

| ESP32-P4 | Subsystem | Baud |
| --- | --- | ---: |
| GPIO21 TX → PA10 RX; GPIO22 RX ← PA9 TX | STM32 drivetrain | 115200 |
| GPIO2 TX → PA10 RX; GPIO1 RX ← PA9 TX | GD32 stepper board | 115200 |
| GPIO27 TX → GPIO2 RX; GPIO47 RX ← GPIO1 TX | ODESC | 115200 |
| GPIO5 TX → BNO RX; GPIO6 RX ← BNO TX | BNO080 | 3000000 |

Connect mower height, turret yaw, and turret pitch to the GD32 **X, Y, and Z** outputs respectively, then label the plugs. The firmware exposes these axes as X/Y/Z.

The hose controller is separate and communicates wirelessly over ESP-NOW. Its firmware uses Wi-Fi channel 6 and the controller MAC configured in [`firmware/esp32-hose/source/main/main.c`](firmware/esp32-hose/source/main/main.c).

#### Pack the main enclosure

The enclosure layout is:

- Red: 36→9 V and 36→24 V converters
- Purple: two BTS7960 drivers
- Yellow: STM32 drivetrain controller
- Green: ESP32-P4
- Black: BNO080, mounted above the ESP32-P4
- White: Waveshare speaker
- Gray: 9→5 V XL4005, insulated against shorts

Main-electronics component layout

Use `wire management cover.stl` to keep motor and encoder wires away from the mower lift ropes. Keep UART and sensor wires away from motor and battery wiring where possible.

<p align="center">
  Main-electronics wiring photo
  Rover electronics before lids
</p>

Fit every lid only after the electrical checks pass.

Rover electronics with lids installed

### 9. First power on

1. Connect to the rover Wi-Fi.
2. From there, you can control each part of the rover.
3. There is a tank drive mode, battery history mode, and sensor mode.
4. You can also record microphone inputs and respond using audio outputs.

### 10. Bonus handheld controller

1. I have also custom-made a handheld controller that connects to the rover, from which you can control the rover, mower, and turret. It is much better than the phone screen for controlling the rover. The controller is part of my Claw Drone project; view how to build it here: [Claw Drone](https://github.com/houseofthe051010/Claw-Drone).

## Flashing the firmware

I have compiled images of firmware for every rover controller in [`firmware/`](firmware/). The `source/` folders also have their code if you want to modify them.

### ESP32-P4 main controller

[`firmware/esp32-p4/images/esp32-p4-complete.bin`](firmware/esp32-p4/images/esp32-p4-complete.bin)

Install [esptool](https://docs.espressif.com/projects/esptool/en/latest/esp32p4/installation.html), connect ESP32-P4, run

```sh
esptool --chip esp32p4 --port COM3 erase-flash
esptool --chip esp32p4 --port COM3 write-flash 0x0 firmware/esp32-p4/images/esp32-p4-complete.bin
```

COM3 Should be replaced with whatever your serial port number is.

### STM32 drivetrain controller

[`firmware/stm32-drive/images/firmware.bin`](firmware/stm32-drive/images/firmware.bin)

You need an **ST-Link** to program the STM32F103. If you are not familiar with connecting an ST-Link, this video shows the wiring and setup:

[**How to connect and use an ST-Link**](https://www.youtube.com/watch?v=KgR3uM21y7o)

1. Connect ST-link to STM32F103
2. Open STM32CubeProgrammer (You need to download this to program it)
3. Connect using ST-Link / SWD.
4. Select `firmware.bin`.
5. Flash it at 0x08000000

### GD32 stepper controller

[`firmware/gd32-stepper/images/GD3P4V1.BIN`](firmware/gd32-stepper/images/GD3P4V1.BIN)

The GD32 Stepper controller has a built-in microSD bootloader, so flashing it is pretty easy

1. Get a FAT32 formatted MicroSD card
2. Copy GD3P4V1.BIN into the card and eject
3. Insert it into the stepper controller
4. Power on the board to load the new firmware 

### ESP32 hose controller

[`firmware/esp32-hose/images/esp32-wroom-hose-complete.bin`](firmware/esp32-hose/images/esp32-wroom-hose-complete.bin)

Connect the ESP32 and run

```sh
esptool --chip esp32 --port COM3 erase-flash
esptool --chip esp32 --port COM3 write-flash 0x0 firmware/esp32-hose/images/esp32-wroom-hose-complete.bin
```

Make sure you use the COM port your esp32 is on and not my COM3

### ODESC V4.2 mower controller

This is the same process as the earlier STM32F103

[`firmware/odesc-v42/images/`](firmware/odesc-v42/images/)

If you are not familiar with connecting an ST-Link, this video shows the wiring and setup:

[**How to connect and use an ST-Link**](https://www.youtube.com/watch?v=KgR3uM21y7o)

1. Connect ST-link to the ODESC board's 5-pin connector that comes with it
2. Open STM32CubeProgrammer (You need to download this to program it)
3. Connect using ST-Link / SWD.
4. Select `firmware.bin`.
5. Flash it at 0x08000000

## What I would do differently next time

- Add cameras and GPS+RTK to the autonomous sensors
- Use stronger drivetrain motors to support a higher speed and better turning (though it would increase the price to build)
- Replace garden hose adapter system with a water tank onboard the rover
- Make a custom PCB that combines all the electronics and sub systems into one board with quick connectors for peripherals (much more expensive though)

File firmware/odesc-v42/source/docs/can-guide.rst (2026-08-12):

.. _can-guide:

================================================================================
CAN Bus Guide for ODrive
================================================================================

.. contents::
   :depth: 1
   :local:
   
ODrive v3 supports CAN 2.0b. We've built a :ref:`simple protocol <can-protocol>` (named CANSimple) so that most ODrive functions can be controlled without a full CAN Open or similar stack.  
This guide is intended for beginners to set up CAN on the ODrive and on their host device.  
We will be focusing on Raspberry Pi and Arduino-compatible devices using the MCP2515 CAN Controller.

What is CAN bus?
--------------------------------------------------------------------------------

Borrowing from `Wikipeda <https://en.wikipedia.org/wiki/CAN_bus>`_:

> A Controller Area Network (CAN bus) is a robust vehicle bus standard designed to allow microcontrollers and devices to communicate with each other's applications without a host computer. 
It is a message-based protocol, designed originally for multiplex electrical wiring within automobiles to save on copper, but it can also be used in many other contexts. 
For each device, the data in a frame is transmitted sequentially but in such a way that if more than one device transmits at the same time, the highest priority device can continue while the others back off. 
Frames are received by all devices, including by the transmitting device.

In simple terms, CAN is a way of communicating between many devices over a single twisted pair of wires. 
The signal is transmitted as the difference in voltage between the two wires (differential signalling), which makes it very robust against noise. 
Instead of using a unique address (like I2C) or a select pin (like SPI), CAN *messages* have a unique ID that also acts as the priority. 
At the beginning of a message frame, all devices talk and read at the same time.  As the message ID is transmitted, the lowest value "wins" and that message will be transmitted (ID **0** has the *highest* priority). 
All other devices will wait for the next chance to send.  If two devices send the same message ID at the same time, they will conflict and a bus failure may occur. 
Make sure your devices can never send the same message ID at the same time!

See also `this great article <https://danfosseditron.zendesk.com/hc/en-gb/articles/360042232992-CAN-bus-physical-layer>`_ from Danfoss that quickly describes how to put together the wiring for a CAN bus 

CAN picture

Why use CAN?
--------------------------------------------------------------------------------

CAN is convenient for its simple and robust Physical Layer (PHY) that requires only a twisted pair of wires and a 120ohm termination resistor at each end. 
It has low jitter and low latency, because there is no host computer.  It is relatively fast (CAN 2.0b supports 1 Mbps).  Messages are easy to configure and load with data. 
Transceivers and controllers are inexpensive and widely available, thanks to its use in automotive.

Hardware Setup
--------------------------------------------------------------------------------

ODrive assumes the CAN PHY is a standard differential twisted pair in a linear bus configuration with 120 ohm termination resistance at each end. 
ODrive versions less than V3.5 include a soldered 120 ohm termination resistor, but ODrive versions V3.5 and greater implement a dip switch to toggle the termination.  
ODrive uses 3.3v as the high output, but conforms to the CAN PHY requirement of achieving a differential voltage > 1.5V to represent a "0".  
As such, it is compatible with standard 5V bus architectures.

Setting up CAN on ODrive
--------------------------------------------------------------------------------

CANSimple breaks the CAN Message ID into two parts:  An axis ID and a command ID.  By default, CAN is enabled on the ODrive, where Axis 0 has ID 0, and Axis 1 has ID 1.  
The ID of each axis should be unique; each should be set via :code:`odrivetool` before connecting to the bus with the command:

.. code:: iPython
    
    <odrv>.<axis>.config.can.node_id = <number>

By default, ODrive supports a value up to 63 (:code:`0x3F`).  See :ref:`can-protocol <can-protocol>` for more information.

You should also set the CAN bus speed on ODrive with the command 

.. code:: iPython
    
    <odrv>.can.config.baud_rate = <number>

.. list-table:: 
   :widths: 25 25
   :header-rows: 1

   * - Speed
     - value
   * - 125 kbps
     - 125000
   * - 250 kbps
     - 250000
   * - 500 kbps
     - 500000
   * - 1000 kbps
     - 1000000

That's it!  You're ready to set up your host device.

Example
~~~~~~~~~~~~~~~~~~~~~~~~~~~~~~~~~~~~~~~~~~~~~~~~~~~~~~~~~~~~~~~~~~~~~~~~~~~~~~~~

.. code:: iPython
    
    odrv0.axis0.config.can.node_id = 0
    odrv0.axis1.config.can.node_id = 1
    odrv0.can.config.baud_rate = 250000

Setting up a Raspberry Pi for CAN Communications
--------------------------------------------------------------------------------

First, you will need a CAN Hat for your Raspberry Pi.  
We are using `this CAN hat <https://www.amazon.com/Raspberry-Long-Distance-Communication-Transceiver-SN65HVD230/dp/B07DQPYFYV>`_.

Setting up the Raspberry Pi essentially involves the following:
#. Enable SPI communications to the MCP2515
#. Install :code:`can-utils` with :code:`apt-get install can-utils`
#. Creating a connection between your application and the :code:`can0` socket

There are many tutorials for this process. 
`This one is pretty good <https://www.hackster.io/youness/how-to-connect-raspberry-pi-to-can-bus-b60235>`_, and `this recent forum post <https://www.raspberrypi.org/forums/viewtopic.php?t=296117>`_ also works.  
However, be careful.  You have to set the correct parameters for the particular CAN hat you're using!

#. Set the correct oscillator value

We configure the MCP2515 in section 2.2 of the tutorial, but the hat we recommend uses a 12MHz crystal instead of a 16 MHz crystal. 
If you're not sure what value to use, the top of the `oscillator <https://en.wikipedia.org/wiki/Crystal_oscillator>`_ will have the value printed on it in MHz.

My Settings:

.. code:: Bash
    
    dtparam=spi-on
    dtoverlay=mcp2515-can0,oscillator=12000000,interrupt=25
    dtoverlay=spi0-hw-cs

#. Use the correct CAN baud rate

By default, ODrive uses 250 kbps (250000) but the tutorial is using 500 kbps.  Make sure you use the value set earlier on the ODrive.

.. code:: Bash

    sudo ip link set can0 up type can bitrate 250000

Wiring ODrive to CAN
~~~~~~~~~~~~~~~~~~~~~~~~~~~~~~~~~~~~~~~~~~~~~~~~~~~~~~~~~~~~~~~~~~~~~~~~~~~~~~~~

The CANH and CANL pins on J2 are used for CAN communication.  Connect CANH to CANH on all other devices, and CANL to CANL.

If your ODrive is the "last" (furthest) device on the bus, you can use the on-board 120 Ohm termination resistor by switching the DIP switch to "CAN 120R". 
Otherwise, add an external resistor.

Follow this recommended wiring schematic for non-isolated systems (most systems):

CAN Wiring

Verifying Communcation
~~~~~~~~~~~~~~~~~~~~~~~~~~~~~~~~~~~~~~~~~~~~~~~~~~~~~~~~~~~~~~~~~~~~~~~~~~~~~~~~

By default, each ODrive axis will send a heartbeat message at 10Hz.  We can confirm our ODrive communication is working by starting the :code:`can0` interface, and then reading from it:

.. code:: Bash

    sudo ip link set can0 up type can bitrate 250000
    candump can0 -xct z -n 10

This will read the first 10 messages from the ODrive and stop.  If you'd like to see all messages, remove the :code:`-n 10` part (hit CTRL+C to exit).  
The other flags (x, c, t) are adding extra information, colouring, and a timestamp, respectively.

.. code:: Bash

    candump can0 -xct z -n 10
    (000.000000)  can0  RX - -  001   [8]  00 00 00 00 01 00 00 00
    (000.001995)  can0  RX - -  021   [8]  00 00 00 00 08 00 00 00
    (000.099978)  can0  RX - -  001   [8]  00 00 00 00 01 00 00 00
    (000.101963)  can0  RX - -  021   [8]  00 00 00 00 08 00 00 00
    (000.199988)  can0  RX - -  001   [8]  00 00 00 00 01 00 00 00
    (000.201980)  can0  RX - -  021   [8]  00 00 00 00 08 00 00 00
    (000.299986)  can0  RX - -  001   [8]  00 00 00 00 01 00 00 00
    (000.301976)  can0  RX - -  021   [8]  00 00 00 00 08 00 00 00
    (000.399986)  can0  RX - -  001   [8]  00 00 00 00 01 00 00 00
    (000.401972)  can0  RX - -  021   [8]  00 00 00 00 08 00 00 00

Alternatively, if you have python can installed (:code:`pip3 install python-can`), you can use the can.viewer script:

:code:`python3 -m can.viewer -c "can0" -i "socketcan"` which will give you a nice readout.  
See the `python-can docs <https://python-can.readthedocs.io/en/master/scripts.html#can-viewer>`_ for an example.

Commanding the ODrive
--------------------------------------------------------------------------------

Now that we've verified the communication is working, we can try commanding the ODrive. 
Make sure your ODrive is configured and working properly over USB with:code:`odrivetool` before continuing. 
See the :ref:`Getting Started Guide <getting-started>` for help with first-time configuration.

To move the ODrive, we use the command :code:`Set Input Pos`, or cmd ID :code:`0x00C`.  First we create a message with this ID, and then "OR" in the axis ID. 
Then we create an 8-byte array of data with input position that we want, with a float value turned into bytes... this can be a pain though.

DBC Files
--------------------------------------------------------------------------------

A DBC file (.dbc) is a database of all the messages and signals in a CAN protocol. 
This file can be used with Python cantools to serialize and deserialize messages without having to handle the bitshifting etc yourself. 
We have generated a .dbc for CANSimple for you!

* `CANSimple DBC File <https://github.com/odriverobotics/ODrive/tree/master/tools/odrive-cansimple.dbc>`_
* `CANSimple DBC Generator Script <https://github.com/odriverobotics/ODrive/tree/master/tools/create_can_dbc.py>`_

Instead of manually writing values into the data, we can create a dictionary of signal:value pairs and serialize the data according to the database definition.

#. Load the database into memory
#. Use :code:`encode_message()` to get a byte array representation of data for sending
#. Use :code:`decode_message()` to get a dictionary representation of data for receiving

The `CAN DBC Example <https://github.com/odriverobotics/ODrive/blob/master/tools/can_dbc_example.py>`_ script shows you how this can be used.  This is the recommended method of serializing and deserializing.

If you're using C++, then you can use the `CANHelpers <https://github.com/odriverobotics/ODrive/blob/master/Firmware/communication/can/can_helpers.hpp>`_ single-header library to do this instead, although the DBC file isn't used.

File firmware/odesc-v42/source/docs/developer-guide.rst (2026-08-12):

.. _developer-guide-doc:

================================================================================
ODrive Firmware Developer Guide
================================================================================

.. contents::
   :depth: 1
   :local:

This guide is intended for developers who wish to modify the firmware of the ODrive.
As such it assumes that you know things like how to use Git, what a compiler is, etc. If that sounds scary, turn around now.

The official releases are maintained on the `master` branch. However since you are a developer, you are encouraged to use the `devel` branch, as it contains the latest features.

The project is under active development, so make sure to check the `Changelog <https://github.com/odriverobotics/ODrive/tree/master/CHANGELOG.md>`_ to keep track of updates.

.. _dev-prereq:

Prerequisites
-------------------------------------------------------------------------------

The recommended tools for ODrive development are:

 * **make**: Used to invoke tup
 * **Tup**: The build system used to invoke the compile commands
 * **ARM GNU Compiler**: For cross-compiling code
 * **ARM GDB**: For debugging the code and stepping through on the device
 * **OpenOCD**: For flashing the ODrive with the STLink/v2 programmer
 * **Python 3**, along with the packages :code:`PyYAML`, :code:`Jinja2` and :code:`jsonschema`: For running the Python tools (:code:`odrivetool`). Also required for compiling firmware.

See below for specific installation instructions for your OS.

Depending on what you're gonna do, you may not need all of the components.

Once you have everything, you can verify the correct installation by running:

.. code:: Bash

  arm-none-eabi-gcc --version
  arm-none-eabi-gdb --version
  openocd --version             # should be 0.10.0 or later
  tup --version                 # should be 0.7.5 or later
  python --version              # should be 3.7 or later

**Installing Prerequisites**

.. tabs::
  .. tab:: Linux (Ubuntu < 20.04)

    .. code:: Bash
      
      sudo add-apt-repository ppa:team-gcc-arm-embedded/ppa

    .. code:: Bash
      
      sudo apt-get update

    .. code:: Bash
      
      sudo apt-get install gcc-arm-embedded

    .. code:: Bash
      
      sudo apt-get install openocd

    .. code:: Bash
      
      sudo apt-get install git-lfs

    .. code:: Bash
      
      sudo add-apt-repository ppa:jonathonf/tup && sudo apt-get update && sudo apt-get install tup

    .. code:: Bash
      
      sudo apt-get install python3 python3-yaml python3-jinja2 python3-jsonschema

  .. tab:: Linux (Ubuntu >= 20.04)

    .. code:: Bash
      
      sudo apt install gcc-arm-none-eabi

    .. code:: Bash
      
      sudo apt install openocd

    .. code:: Bash
      
      sudo apt install git-lfs

    .. code:: Bash
      
      sudo apt install tup

    .. code:: Bash
      
      sudo apt install python3 python3-yaml python3-jinja2 python3-jsonschema

  .. tab:: Arch Linux

    .. code:: Bash
      
      sudo pacman -S arm-none-eabi-gcc arm-none-eabi-binutils

    .. code:: Bash
      
      sudo pacman -S arm-none-eabi-gdb

    .. code:: Bash
      
      sudo pacman -S git-lfs

    .. code:: Bash
      
      sudo pacman -S tup

    .. code:: Bash
      
      sudo pacman -S python python-yaml python-jinja python-jsonschema

    * `OpenOCD AUR package <https://aur.archlinux.org/packages/openocd/>`__

  .. tab:: Mac
    First install `Homebrew <https://brew.sh/>`__ Then you can run these commands in Terminal:

    .. code:: Bash
      
      brew install armmbed/formulae/arm-none-eabi-gcc

    .. code:: Bash
      
      brew install --cask osxfuse && brew install tup

    .. code:: Bash
      
      brew install openocd

    .. code:: Bash
      
      brew install git-lfs

    .. code:: Bash
      
      pip3 install PyYAML Jinja2 jsonschema

  .. tab:: Windows

    .. note:: make sure these programs are not only installed but also added to your `PATH`.

    Some instructions in this document may assume that you're using a bash command prompt, such as the Windows 10 built-in bash or `Git <https://git-scm.com/download/win>`__ bash.

    * `ARM compiler <https://developer.arm.com/open-source/gnu-toolchain/gnu-rm/downloads>`__

      .. note:: 

        After installing, create an environment variable named `ARM_GCC_ROOT` whose value is the path you installed to.  e.g. :code:`C:\Program Files (x86)\GNU Tools Arm Embedded\7 2018-q2-update`.  
        This variable is used to locate include files for the c/c++ Visual Studio Code extension.

      .. note:: 8-2018-q4-major seems to have a bug on Windows.  Please use 7-2018-q2-update.
    * `Tup <http://gittup.org/tup/index.html>`__
    * `GNU MCU Eclipse's Windows Build Tools <https://github.com/gnu-mcu-eclipse/windows-build-tools/releases>`__
    * `Python 3 <https://www.python.org/downloads/>`__
      * Install Python packages: :code:`pip install PyYAML Jinja2 jsonschema`
    * `OpenOCD <https://github.com/xpack-dev-tools/openocd-xpack/releases/>`__
    * `ST-Link/V2 Drivers <https://www.st.com/content/st_com/en/products/development-tools/software-development-tools/stm32-software-development-tools/stm32-utilities/stsw-link009.html>`__

Configuring the Build
--------------------------------------------------------------------------------

To customize the compile time parameters, copy or rename the file :code:`Firmware/tup.config.default` to :code:`Firmware/tup.config` and edit the following parameters in that file:

* **CONFIG_BOARD_VERSION** The board version you're using. Can be `v3.1`, `v3.2`, `v3.3`, `v3.4-24V`, `v3.4-48V`, `v3.5-24V`, `v3.5-48V`, etc. Check for a label on the upper side of the ODrive to find out which version you have. 
  Some ODrive versions don't specify the voltage: in that case you can read the value of the main capacitors: 120uF are 48V ODrives, 470uF are 24V ODrives.

* **CONFIG_DEBUG** Defines whether debugging will be enabled when compiling the firmware; specifically the :code:`-g -gdwarf-2` flags. 
  Note that printf debugging will only function if your tup.config specifies the :code:`USB_PROTOCOL` or :code:`UART_PROTOCOL` as stdout and :code:`DEBUG_PRINT` is defined. 
  See the IDE specific documentation for more information.

You can also modify the compile-time defaults for all :code:`.config` parameters. 
You will find them if you search for :code:`AxisConfig`, :code:`MotorConfig`, etc.

.. _build-and-flash:

Building and Flashing the Firmware
--------------------------------------------------------------------------------

#. Run :code:`make` in the :code:`Firmware` directory.
#. Connect the ODrive via USB and power it up.
#. Flash the firmware using :ref:`odrivetool dfu <firmware-update>`.

.. _flashing-with-an-stlink: 

Flashing using an STLink/v2 
~~~~~~~~~~~~~~~~~~~~~~~~~~~~~~~~~~~~~~~~~~~~~~~~~~~~~~~~~~~~~~~~~~~~~~~~~~~~~~~~

* Connect `GND`, `SWD`, and `SWC` on connector J2 to the programmer. 

  .. note:: Always plug in `GND` first!

* You need to power the board by only **ONE** of the following: VCC(3.3v), 5V, or the main power connection (the DC bus). The USB port (J1) does not power the board.
* Run :code:`make flash` in the :code:`Firmware` directory.

.. note:: If you receive the error `can't find target interface/stlink-v2.cfg` or similar, create and set an environment variable named :code:`OPENOCD_SCRIPTS` to the location of the openocd scripts directory.

If the flashing worked, you can connect to the board using the :ref:`odrivetool <odrivetool-startup>`.

Testing
--------------------------------------------------------------------------------

.. include:: testing.rst

Debugging
--------------------------------------------------------------------------------

If you're using VSCode, make sure you have the Cortex Debug extension, OpenOCD, and the STLink.  
You can verify that OpenOCD and STLink are working by ensuring you can flash code.  
Open the ODrive_Workspace.code-workspace file, and start a debugging session (F5).  
VSCode will pick up the correct settings from the workspace and automatically connect.  
Breakpoints can be added graphically in VSCode.

* Run :code:`make gdb`. This will reset and halt at program start. Now you can set breakpoints and run the program. If you know how to use gdb, you are good to go.

Setting up an IDE
--------------------------------------------------------------------------------

For working with the ODrive code you don't need an IDE, but the open-source IDE VSCode is recommended.  
It is also possible to use Eclipse. If you'd like to go that route, please see the respective configuration document:

* :ref:`Configuring VSCode <configuring-vscode>`
* :ref:`Configuring Eclipse <configuring-eclipse>`

STM32CubeMX
--------------------------------------------------------------------------------

This project uses the STM32CubeMX tool to generate startup code and to ease the configuration of the peripherals. 
You can download it from `here <http://www2.st.com/content/st_com/en/products/development-tools/software-development-tools/stm32-software-development-tools/stm32-configurators-and-code-generators/s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>`___. 
All CubeMX related files are in :code:`Firmware/Board/v3`.

You will likely want the pinout for this process. It is available `here <https://docs.google.com/spreadsheets/d/1QXDCs1IRtUyG__M_9WruWOheywb-GhOwFtfPcHuN2Fg/edit#gid=404444347>`__.

Maintaining Modified Generated Code
~~~~~~~~~~~~~~~~~~~~~~~~~~~~~~~~~~~~~~~~~~~~~~~~~~~~~~~~~~~~~~~~~~~~~~~~~~~~~~~~

When generating the code, STM32CubeMX will nuke everything except some special sections that they provide. 
These sections are marked like `USER CODE BEGIN`...`USER CODE END`.
We used to try to make sure all edits we made to the generated code would only go in these sections, so some code structrure may reflect that.
However over time we realized this will not be tenable, so instead we use git to rebase all changes of the generated code whenever we need to regenerate it.
We use two special branches that will help us to do this, they are :code:`STM32CubeMX-start` and :code:`STM32CubeMX-end`.
How to use these is shown in the following example.

.. note:: 
  Due to how this rebasing is done, all development that changes the generated code should be done directly on :code:`STM32CubeMX-end`, and not based on :code:`devel`, then follow step 4 below to carry them over to your feature branch. If you did some changes to the generated code based from :code:`devel`, you need to cherry pick just those changes over to :code:`STM32CubeMX-end`.

#. **Ensuring a clean slate**

  * We do all changes to the STM32CubeMX config and regenerate the code on top of :code:`STM32CubeMX-start`.
    * :code:`git checkout STM32CubeMX-start`

  * Run stm32cubeMX and load the :code:`Firmware/Board/v3/Odrive.ioc` project file.
    * If the tool asks if you wish to migrate to a new version, choose to download the old firmware package (unless you want to use the latest libraries)
  
  * Without changing any settings, press :code:`Project -> Generate code`.
  * You may need to let it download some drivers and such.
  * STM32CubeMX may now have a newer version of some of the libraries, so there may be changes to the generated code even though we didn't change any settings. We need to check that everything is still working, and hence check in the changes:
  * :code:`git config --local core.autocrlf input` - This will tell git that all files should be checked in with LF endings (CubeMX generates CRLF endings).
  * :code:`git diff` - Ignore the pile of line ending warnings.
  * If you feel qualified: you can now ispect if CubeMX introduced something stupid. If there were any changes, and they look acceptable, we should commit them:
    
    * :code:`git commit -am "Run STM32CubeMX v1.21"` - Replace with actual version of CubeMX

#. **Making Changes to the STM32CubeMX Config**

  * After completing the above steps, make sure the working directory is clean:
    * :code:`git status` should include "nothing to commit, working tree clean"

  * Make your changes in STM32CubeMX, save the project and generate the code. (:code:`Project -> Generate code`)
  * :code:`git diff` - Check that the introduced changes are as expected
  * If everything looks ok, you can commit your changes.

#. **Rebasing the Modifications to the Generated Code**

  * :code:`git checkout STM32CubeMX-end`
  * :code:`git rebase STM32CubeMX-start`
  * Make sure the rebase finishes, fixing any conflicts that may arise

#. **Merge New STM32CubeMX Code to your Feature Branch**

  Simply merge the new state at:code: `STM32CubeMX-end` into your feature branch.
  * :code:`git checkout your-feature`
  * :code:`git merge STM32CubeMX-end`

#. **Pushing back Upstream**

  * Generate a PR like normal for your feature.
  * Make sure youhave pushed to the :code:`STM32CubeMX-start` and :code:`STM32CubeMX-end` branches on your fork.
  * Make a note in your PR to the maintainer that they need to update the STM32CubeMX branches when they merge the PR.

Troubleshooting
--------------------------------------------------------------------------------

:code:`LIBUSB_ERROR_IO` when flashing with the STLink/v2
~~~~~~~~~~~~~~~~~~~~~~~~~~~~~~~~~~~~~~~~~~~~~~~~~~~~~~~~~~~~~~~~~~~~~~~~~~~~~~~~

**Problem:** when I try to flash the ODrive with the STLink using :code:`make flash` I get this error:

.. code:: Bash

  Open On-Chip Debugger 0.10.0
  Licensed under GNU GPL v2
  For bug reports, read
    http://openocd.org/doc/doxygen/bugs.html
  Info : auto-selecting first available session transport "hla_swd". To override use 'transport select <transport>'.
  Info : The selected transport took over low-level target control. The results might differ compared to plain JTAG/SWD
  adapter speed: 2000 kHz
  adapter_nsrst_delay: 100
  none separate
  Info : Unable to match requested speed 2000 kHz, using 1800 kHz
  Info : Unable to match requested speed 2000 kHz, using 1800 kHz
  Info : clock speed 1800 kHz
  Error: libusb_open() failed with LIBUSB_ERROR_IO
  Error: open failed
  in procedure 'init' 
  in procedure 'ocd_bouncer'

**Solution:**
This happens from time to time.

#. Unplug the STLink and all ODrives from your computer
#. Power off the ODrive you're trying to flash
#. Plug in the STLink into your computer
#. Power on the ODrive
#. Run :code:`make flash` again

:code:`Cannot identify target as a STM32 family` when flashing using openocd
~~~~~~~~~~~~~~~~~~~~~~~~~~~~~~~~~~~~~~~~~~~~~~~~~~~~~~~~~~~~~~~~~~~~~~~~~~~~~~~~

**Problem:** When I try to flash ODrive v4.1 with :code:`make flash` then I get:

.. code:: Bash

  [...]
  ** Programming Started **
  auto erase enabled
  Info : device id = 0x10006452
  Warn : Cannot identify target as a STM32 family.
  Error: auto_probe failed
  embedded:startup.tcl:487: Error: ** Programming Failed **
  in procedure 'program' 
  in procedure 'program_error' called at file "embedded:startup.tcl", line 543
  at file "embedded:startup.tcl", line 487

**Solution:**
Compile and install a recent version of openocd from source. 
The latest official release (0.10.0 as of Nov 2020) doesn't support the STM32F722 yet.

.. code:: Bash

  sudo apt-get install libtool libusb-1.0
  git clone https://git.code.sf.net/p/openocd/code openocd
  cd openocd/
  ./bootstrap
  ./configure --enable-stlink
  make
  sudo make install

Documentation
--------------------------------------------------------------------------------
.. admonition:: In Progress 

  ODrive documentation is now built using `Sphinx <https://www.sphinx-doc.org/en/master/>`_.

  * Prerequisites:

    * Install Sphinx: :code:`pip install -U sphinx`
    * Install packages: :code:`pip install sphinx-copybutton sphinx-panels sphinx-rtd-theme`

  * Run :code:`make html` within the :kbd:`./docs/reStructuredText` folder 
  * Open :kbd:`./docs/reStructuredText/_build/index.html` to view

.. _modifying-libfibre:

Modifying libfibre
--------------------------------------------------------------------------------

If you need to modify libfibre add :code:`CONFIG_BUILD_LIBFIBRE=true` to your tup.config and rerun :code:`make`. 
After this you can start :code:`odrivetool` (on your local PC) and it will use the updated libfibre.

To cross-compile libfibre for the Raspberry Pi, run :code:`make libfibre-linux-armhf` or :code:`make libfibre-all`. 
This will require a docker container. See ;:ref:`fibre-cpp readme <../Firmware/fibre-cpp/README.md>` for details.

.. code:: Bash

  docker run -it -v "$(pwd)":/build -v /tmp/build:/build/build -w /build fibre-compiler configs/linux-armhf.config

If you're satisfied with the changes don't forget to generate binaries for all
supported systems using :code:`make libfibre-all`.

Releases
--------------------------------------------------------------------------------

We use GitHub Releases to provide firmware releases.

#. Cut off the changelog to reflect the new release
#. Merge the release candidate into master.
#. Push a (lightweight) tag to the master branch. Follow the existing naming convention.
#. If you changed something in libfibre, regenerate the binaries using :code:`make libfibre-all`. 
   See :ref:`Modifying libfibre <modifying-libfibre>` for details.
#. Push the python tools to PyPI (see setup.py for details).
#. Edit the release on GitHub to add a title and description (copy&paste from changelog).

Code Maintenance Notes
--------------------------------------------------------------------------------

The cortex M4F processor has hardware single precision float unit. However double precision operations are not accelerated, and hence should be avoided. 
The following regex is helpful for cleaning out double constants:

find: 

.. code::

  ([-+]?[0-9]+\.[0-9]+(?:[eE][-+]?[0-9]+)?)([^f0-9e])

replace: 

  .. code::

    \1f\2

Notes for Contributors
--------------------------------------------------------------------------------

In general the project uses the `Google C++ Style Guide <https://google.github.io/styleguide/cppguide.html>`__ with a few exceptions:

 * The default indentation is 4 spaces.
 * The 80 character limit is not very strictly enforced, merely encouraged.
 * The file extensions `*.cpp` and `*.hpp` are used instead of `*.cc` and `*.h`.

Your help is welcome! However before you start working on a feature/change that will take you a non-negligible amount of time and that you plan to upstream please discuss your plans with us on GitHub or Discord. 
This will ensure that your implementation is in line with the direction that ODrive is going.

When filing a PR please go through this checklist:

 * Make sure you adhere to the same coding style that we use (see note above).
 * Update CHANGELOG.md.
 * If you removed/moved/renamed things in :code:`odrive-interface.yaml` make sure to add corresponding bullet points tp the "API migration notes" section in the changelog. Use git to compare against the :code:`devel` branch.
 * Also, for each removed/moved/renamed API item use your IDE's search feature to search for occurrences of this name. Update the places you found (this will usually be documentation and test scripts).
 * If you added things to :code:`odrive-interface.yaml` make sure the new things have decent documentation in the YAML file. We don't expect 100% coverage but use good sense of what to document.
 * Make sure your PR doesn't contain spurious changes that unnecessarily add or remove whitespace. These add noise and make the reviewer's lifes harder.
 * If you changed any enums in :code:`odrive-interface.yaml`, make sure you update `enums.py <https://github.com/odriverobotics/ODrive/blob/master/tools/odrive/enums.py>`_ and `ODriveEnums.h <https://github.com/odriverobotics/ODrive/blob/master/Arduino/ODriveArduino/ODriveEnums.h>`_. 
   The file includes instructions on how to do this. Check the diff to verify that none of the existing enumerators changed their value.

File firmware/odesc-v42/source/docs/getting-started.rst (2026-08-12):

================================================================================
Getting Started
================================================================================

.. contents::
   :depth: 1
   :local:

Hardware Requirements
--------------------------------------------------------------------------------

**You will need**

* One or two `brushless motors <https://docs.google.com/spreadsheets/d/12vzz7XVEK6YNIOqH0jAz51F5VUpc-lJEs3mmkWP1H4Y>`__. It is fine, even recommended, to start testing with just a single motor and encoder.
* One or two `encoder(s) <https://docs.google.com/spreadsheets/d/1OBDwYrBb5zUPZLrhL98ezZbg94tUsZcdTuwiVNgVqpU>`__.
* A power supply (12V-24V for the 24V board variant, 12V-56V for the 56V board variant). A battery is also fine. Some advice on choosing a power supply can be found `here <https://things-in-motion.blogspot.com/2018/12/how-to-select-right-power-source-for.html>`__.

.. dropdown:: What voltage variant do I have?

    On all ODrives shipped July 2018 or after have a silkscreen label clearly indicating the voltage variant.

    ODrives before this may or may not have this label. If you don't have a label, then you can look at the bus capacitors (8 gray cylinder components on the underside of the board). If they read 470uF, you have a 24V version; if they read 120uF you have a 48V version.
 
* A power resistor. A good starting point would be the 50W resistor included with your ODrive.

.. dropdown:: Do I really need a power resistor? What values to choose?

    If you don't have a brake resistor, the ODrive will pump excess power back into the power supply during deceleration to achieve the desired deceleration torque. If your power supply doesn't eat that power (which it won't if it's not a battery), the bus voltage will inevitebly rise. If you're unlucky this will break the power supply.
    At some point, the ODrive's overvoltage protection will trip, after which both motors will be allowed to spin freely. Depending on your machine, this may or may not be a problem.

    The power resistor values you need depends on your motor setup, and peak/average deceleration power.

    To be on the safe side, think about what speed and current limits you want to set for the motor.

    When braking at max speed and with maximum motor current, the power that is dissipated in the power resistor can be calulated as: `P_brake = V_emf * I_motor` where `V_emf = motor_rpm / motor_kv`.

Wiring up the ODrive
~~~~~~~~~~~~~~~~~~~~~~~~~~~~~~~~~~~~~~~~~~~~~~~~~~~~~~~~~~~~~~~~~~~~~~~~~~~~~~~~

.. warning:: Firmware, software, and documentation is intended for use with ODrive motor controllers purchased from odriverobotics.com. ODrive Robotics does not sell products through any channel other than odriverobotics.com. We do not provide support for ODrives purchased elsewhere.

.. warning:: Make sure you have a good mechanical connection between the encoder and the motor, slip can cause disastrous oscillations or runaway.

All non-power I/O is 3.3V output and 5V tolerant on input, on ODrive v3.3 and newer.

Wiring up the motors
********************************************************************************

Connect the motor phases into the 3-phase screw terminals. It is not recommended to use a clip-on connector such as an alligator clip, as this can cause issues with the phase resistance/inductance measurements. 

Wiring up the encoders
********************************************************************************

Connect the encoder(s) to J4. The A,B phases are required, and the Z (index pulse) is optional. The A,B and Z lines have 3.3k pull up resistors, for use with open-drain encoder outputs. For single ended push-pull signals with weak drive current (\<4mA), you may want to desolder the pull-ups.



Safety & Power UP
********************************************************************************
.. warning:: Always think safety before powering up the ODrive if motors are attached. Consider what might happen if the motor spins as soon as power is applied.

* Unlike some devices, the ODrive does not recieve power over the USB port so the 24/56 volt power input is required even just to communicate with it using USB. It is ok to power up the ODrive before or after connecting the USB cable.

* To power up the ODrive, connect the power source to the DC terminals. Make sure to pay attention to the polarity. Try to connect the power source first and then turn it on to avoid inrush current. If this can't be avoided then a small spark is normal. This is caused by the capacitors charging up.

* Make sure to avoid a ground loop! See the :ref:`ground loop page <ground-loops>` for details.

.. _install-odrivetool:

Downloading and Installing :code:`odriveool`
~~~~~~~~~~~~~~~~~~~~~~~~~~~~~~~~~~~~~~~~~~~~~~~~~~~~~~~~~~~~~~~~~~~~~~~~~~~~~~~~

Most instructions in this guide refer to a utility called `odrivetool`, so you should install that first.

.. tabs::
    .. tab:: Windows

        #. Install Python 3

            We recommend the Anaconda distribution because it packs a lot of useful scientific tools, however you can also install the standalone python.
            
            * **Anaconda**: Download the installer from `here <https://www.anaconda.com/download/#windows>`__. Execute the downloaded file and follow the instructions.
            * **Standalone Python**: Download the installer for 3.8.6 from `here <https://www.python.org/downloads/release/python-386/>`__. Execute the downloaded file and follow the instructions.  As of Oct 2020, Matplotlib (required by odrivetool) had not been updated to work with 3.9, so please use 3.8.6.
            * If you have Python 2 installed alongside Python 3, replace :code:`pip` by :code:`C:\Users\YOUR_USERNAME\AppData\Local\Programs\Python\Python36-32\Scripts\pip`. If you have trouble with this step then refer to `this walkthrough <https://www.youtube.com/watch?v=jnpC_Ib_lbc>`__.

        #. Launch the command prompt.

            * **Anaconda**: In the start menu, type :code:`Anaconda Prompt` :kbd:`Enter`
            * **Standalone Python** In the start menu, type :code:`cmd` :kbd:`Enter`

        #. Install odrivetool by running      

            .. code-block:: Bash
                
                pip install --upgrade odrive

    .. tab:: macOS

        We are going to run the following commands for installation in Terminal.

        #. If you don't already have it, install homebrew: 

            .. code-block:: Bash

                /usr/bin/ruby -e "$(curl -fsSL https://raw.githubusercontent.com/Homebrew/install/master/install)"

        #. Install python:

            .. code-block:: Bash

                brew install python

            .. note::
                If you get an error saying `python 2.7.* is already installed`, then upgrade to Python 3 by running:  

                .. code-block:: Bash

                    brew upgrade python

        #. Install libusb:

            libusb is required for odrivetool to communicate with the ODrive:
        
            .. code-block:: Bash

                brew install libusb

            .. _installodrivetool:

        #. Install odrivetool:

            Now that you have Python 3 and all the package managers, run:
        
            .. code-block:: Bash

                pip3 install --upgrade odrive

        **Troubleshooting**

        #. Permission Errors:

            Just run the previous command in sudo

            .. code-block:: Bash

                sudo pip3 install --upgrade odrive

        #. Dependency Errors:

            If the installer doesn't complete and you get a dependency error (Ex. :code:`No module...`` or :code:`module_name not found`), run the command
            
            .. code-block:: Bash

                sudo pip3 install module_name

            and try to :ref:`install odrivetool <installodrivetool>` again.

        #. Other Install Errors: 

            If the installer fails at installing dependencies, try

            .. code-block:: Bash

                sudo pip3 install odrive --no-deps

            .. warning:: If you do this, brace yourself for runtime errors when you run :code:`odrivetool` (the basic functionality should work though).

    .. tab:: Linux

        #. `Install Python 3 <https://www.python.org/downloads/>`__. 
        
            For example, on Ubuntu, run

            .. code-block:: Bash

                sudo apt install python3 python3-pip

        #. Install odrivetool by opening a terminal and typing

            .. code-block:: Bash

                sudo pip3 install --upgrade odrive

            .. note:: This should automatically add the udev rules. If this fails for some reason you can add them manually:

                .. code-block:: Bash

                    echo 'SUBSYSTEM=="usb", ATTR{idVendor}=="1209", ATTR{idProduct}=="0d[0-9][0-9]", MODE="0666"' | sudo tee /etc/udev/rules.d/91-odrive.rules
                    sudo udevadm control --reload-rules
                    sudo udevadm trigger

        .. admonition:: **Ubuntu**, **Raspbian**

            If you can't invoke :code:`odrivetool` at this point, try adding :code:`~/.local/bin` to your :code:`$PATH`, `see related bug <https://unix.stackexchange.com/a/392710/176715>`__. 
            This is done for example by running :code:`nano ~/.bashrc`, scrolling to the bottom, pasting :code:`export PATH=$PATH:~/.local/bin`, and then saving and closing, then close and reopen the terminal window.

Firmware
~~~~~~~~~~~~~~~~~~~~~~~~~~~~~~~~~~~~~~~~~~~~~~~~~~~~~~~~~~~~~~~~~~~~~~~~~~~~~~~~

To simplify the start up procedure we suggest using the latest firmware verion. Please follow the instructions :ref:`here <firmware-update>` to make sure your firmware is up to date.

.. admonition:: **ODrive v3.5 and later**

    Your board should come preflashed with the latest firmware. If you run into problems, check your firmware version and upgrade if possible.

.. admonition:: **ODrive v3.4 and earlier**

    Your board does **not** come preflashed with any firmware. Follow the instructions :ref:`here <st-link-flash>` on the ST Link procedure before you continue.

.. _odrivetool-startup:

Start :code:`odrivetool`
--------------------------------------------------------------------------------

* To launch the main interactive ODrive tool, type :code:`odrivetool` and :kbd:`Enter`. 
* Connect your ODrive and wait for the tool to find it. If it dos not connect after a few seconds refer to the :ref:`troubleshooting guide <troubleshooting>`. 
* Now you can, for instance type :code:`odrv0.vbus_voltage` :kbd:`Enter` to inspect the boards main supply voltage.

It should look something like this:

.. code:: iPython

    ODrive control utility v0.5.4
    Please connect your ODrive.
    Type help() for help.

    Connected to ODrive 306A396A3235 as odrv0
    In [1]: odrv0.vbus_voltage
    Out[1]: 11.97055721282959

The tool you're looking at is a fully capable Python command prompt, so you can type any valid python code.
You can read more about :code:`odrivetool` :ref:`here <odrivetool-doc>`.

.. _motor-config:

Motor Configuration
--------------------------------------------------------------------------------

.. warning:: Read this section carefully, else you risk breaking something.

Configuration of a motor is done within the :code:`odrivetool` console, type :code:`odrivetool` and :kbd:`Enter` to launch. Make sure you have completed :ref:` Start odrivetool <odrivetool-startup>` before continuing.

This section assumes that the motor being configured is connected to the ODrive as M0 (:code:`axis0`). To configure M1, simply replace all instances of :code:`axis0` with :code:`axis1`. 

If any of the following steps fail, print the errors by running :code:`dump_errors(odrv0)` and refer to the :ref:`Error codes <error-codes>` section for debugging.
Once the error(s) have been identified and corrected, run :code:`odrv0.clear_errors()` to clear them before moving forward.

.. admonition:: Working on a hoverboard?

    There is a :ref:`separate guide <hoverboard-doc>` specifically for hoverboard motors

Setting the Limits
~~~~~~~~~~~~~~~~~~~~~~~~~~~~~~~~~~~~~~~~~~~~~~~~~~~~~~~~~~~~~~~~~~~~~~~~~~~~~~~~

With :code:`odrivetool` open you can assign variables directly by name.
For instance, to set the current limit of M0 to 10A you would type

.. code:: iPython

    odrv0.axis0.motor.config.current_lim = 10

Current limit
*********************************************************************************

    The default current limit, for safety reasons, is set to 10A. This is quite weak, but good for making sure the drive is stable. 
    To change the current limit, 

    .. code:: iPython

        odrv0.axis0.motor.config.current_lim = val

    Once you have tuned the ODrive, you can increase this to 60A to increase performance.   

    .. dropdown:: Need more than 60A?

        For current limits above 60A, you must change the current amplifier gains. 
        You do this by requesting a different current range. i.e. for 90A on M0

        .. code:: iPython

            odrv0.axis0.motor.config.requested_current_range = 90   

        then :ref:`save the configuration and reboot <save-config>` as the gains are written out to the DRV (MOSFET driver) only during startup.
    
    .. Note:: The motor current and the current drawn from the power supply is not the same in general. You should not look at the power supply current to see what is going on with the motor current.*

        .. dropdown:: Ok, so tell me how it actually works then...

            The current in the motor is only connected to the current in the power supply `sometimes` and other times it just cycles out of one phase and back in the other. 
            This is what the modulation magnitude is (sometimes people call this duty cycle, but that's a bit confusing because we use `SVM <https://www.mathworks.com/solutions/power-electronics-control/space-vector-modulation.html>`__ not straight PWM). 
            When the modulation magnitude is 0, the average voltage seen across the motor phases is 0, and the motor current is never connected to the power supply. 
            When the magnitude is 100%, it is always connected, and at 50% it's connected half the time, and cycled in just the motor half the time.

            The largest effect on modulation magnitude is speed. There are other smaller factors, but in general: if the motor is still it's not unreasonable to have 50A in the motor from 5A on the power supply. 
            When the motor is spinning close to top speed, the power supply current and the motor current will be somewhat close to each other.

Velocity limit
*********************************************************************************

The motor will be limited to this speed in [turn/s]. Again the default value is quite slow.

.. code:: iPython
    
    odrv0.axis0.controller.config.vel_limit = 2

Calibration Current
*********************************************************************************

You can change :code:`odrv0.axis0.motor.config.calibration_current` [A] to the largest value you feel comfortable leaving running through the motor continuously when the motor is stationary. 
If you are using a small motor (i.e. 15A current rated) you may need to reduce :code:`calibration_current` to a value smaller than the default.

Setting Other Hardware Parameters
~~~~~~~~~~~~~~~~~~~~~~~~~~~~~~~~~~~~~~~~~~~~~~~~~~~~~~~~~~~~~~~~~~~~~~~~~~~~~~~~

Enable Brake Resistor
*********************************************************************************

Set this to `True` if using a brake resistor. You need to :ref:`save the configuration and reboot <save-config>` the ODrive for this to take effect.

.. code:: iPython

    odrv0.config.enable_brake_resistor

Brake Resistor Value
*********************************************************************************

This is the resistance [Ohms] of the brake resistor. You can leave this at the default setting if you are not using a brake resistor.

.. code:: iPython
    
    odrv0.config.brake_resistance

.. note:: There may be some extra resistance in your wiring and in the screw terminals, so if you are getting issues while braking you may want to increase this parameter by around 0.05 ohm.

Negative Current
*********************************************************************************

This is the amount of current [Amps] allowed to flow back into the power supply. The convention is that it is negative. By default, it is set to a conservative value of 10mA. If you are using a brake resistor and getting :code:`DC_BUS_OVER_REGEN_CURRENT` errors, raise it slightly. 
If you are not using a brake resistor and you intend to send braking current back to the power supply, set this to a safe level for your power source.

.. code:: iPython

    odrv0.config.dc_max_negative_current

Pole Pairs
*********************************************************************************

This is the number of **magnet poles** in the rotor, **divided by two**. To find this, you can simply count the number of permanent magnets in the rotor, if you can see them.

.. code:: iPython
    
    odrv0.axis0.motor.config.pole_pairs

.. Note:: This is **not** the same as the number of coils in the stator.

A good way to find the number of pole pairs is with a current limited power supply. Connect any two of the three phases to a power supply outputting around 2A, spin the motor by hand, and count the number of detents. 
This will be the number of pole pairs. If you can't distinguish the detents from the normal cogging present when the motor is disconnected, increase the current.
Another way is sliding a loose magnet in your hand around the rotor, and counting how many times it stops. This will be the number of `pole pairs`. If you use a ferrous piece of metal instead of a magnet, you will get the number of `magnet poles`.

Torque Constant
*********************************************************************************

This is the ratio of torque produced by the motor per Amp of current delivered to the motor. This should be set to **8.27 / (motor KV)**.

.. code:: iPython
    
    odrv0.axis0.motor.config.torque_constant

If you decide that you would rather command torque in units of Amps, you could simply set the torque constant to 1.

Motor Type
*********************************************************************************

This is the type of motor being used. Currently two types of motors are supported: High-current motors (`MOTOR_TYPE_HIGH_CURRENT, [0]`) and gimbal motors (`MOTOR_TYPE_GIMBAL, [2]`).

.. code:: iPython

    odrv0.axis0.motor.config.motor_type

.. dropdown:: Which :code:`motor_type` to choose?

    If you're using a regular hobby brushless motor like `this <https://hobbyking.com/en_us/turnigy-aerodrive-sk3-5065-236kv-brushless-outrunner-motor.html>`__ one, you should set :code:`motor_mode` to :code:`MOTOR_TYPE_HIGH_CURRENT`. 
    For low-current gimbal motors like `this <https://hobbyking.com/en_us/turnigy-hd-5208-brushless-gimbal-motor-bldc.html>`__ one, you should choose :code:`MOTOR_TYPE_GIMBAL`. Do not use :code:`MOTOR_TYPE_GIMBAL` on a motor that is not a gimbal motor, as it may overheat the motor or the ODrive.

    **Further detail:**
    If 100's of mA of current noise is "small" for you, you can choose :code:`MOTOR_TYPE_HIGH_CURRENT`.
    If 100's of mA of current noise is "large" for you, and you do not intend to spin the motor very fast (Ω * L << R), and the motor is fairly large resistance (1 ohm or larger), you can chose :code:`MOTOR_TYPE_GIMBAL`.
    If 100's of mA current noise is "large" for you, `and` you intend to spin the motor fast, then you need to replace the shunt resistors on the ODrive.

.. note:: 
    When using gimbal motors, :code:`current_lim` `and` :code:`calibration_current` actually mean `voltage limit` and `calibration voltage` respectively, since we don't use current feedback. 
    This means that if you set it to 10, it means 10V, despite the name of the parameter.

Motor Thermistor
*********************************************************************************

If using motor thermistor please see the :ref:`thermistors <thermistor-doc>` page for setup.

Encoder Configuration
--------------------------------------------------------------------------------

With Encoder
~~~~~~~~~~~~~~~~~~~~~~~~~~~~~~~~~~~~~~~~~~~~~~~~~~~~~~~~~~~~~~~~~~~~~~~~~~~~~~~~

Set the encoder count per revolution [CPR] value

.. code:: iPython
    
    odrv0.axis0.encoder.config.cpr

This is 4x the Pulse Per Revolution (PPR) value. Usually this is indicated in the datasheet of your encoder.
If you purchased an encoder from our shop, you can find the parameters `here <https://docs.google.com/spreadsheets/d/1OBDwYrBb5zUPZLrhL98ezZbg94tUsZcdTuwiVNgVqpU/edit#gid=0>`__.

Without Encoder
~~~~~~~~~~~~~~~~~~~~~~~~~~~~~~~~~~~~~~~~~~~~~~~~~~~~~~~~~~~~~~~~~~~~~~~~~~~~~~~~

* If you wish to run in sensorless mode, please see :ref:`Setting up sensorless. <sensorless-setup>`
* If you are using hall sensor feedback, please see the :ref:`hoverboard motor example <hoverboard-doc>`.

.. _save-config:

Save Configuration
--------------------------------------------------------------------------------

You can save all :code:`.config` parameters to persistent memory so the ODrive remembers them between power cycles. This will reboot the board.

.. code:: iPython
    
    odrv0.save_configuration() 

Position control of M0
--------------------------------------------------------------------------------
Let's get motor 0 up and running. The procedure for motor 1 is exactly the same, so feel free to substitute :code:`axis1` wherever it says :code:`axis0`.

    #. Start the calibratrion sequence by entering

    .. code:: iPython
        
        odrv0.axis0.requested_state = AXIS_STATE_FULL_CALIBRATION_SEQUENCE
        
    and press :kbd:`Enter`. 

    After about 2 seconds you should hear a beep. Then the motor will turn slowly in one direction for a few seconds, then back in the other direction.

    .. dropdown:: What's the point of this?

        This procedure first measures your motor's electrical properties (namely phase resistance and phase inductance) and then the offset between the motor's electrical phase and the encoder position.

    The startup procedure is demonstrated `here <https://www.youtube.com/watch?v=VCX1bA2xnuY>`__.

    .. note::
        The rotor must be allowed to rotate without any biased load during startup. 
        That means mass and weak friction loads are fine, but gravity or spring loads are not okay. 
        Also note that in the video, the motors spin after initialization, but in the current software the default behaviour is not like that.

    .. dropdown:: Help, something isn't working!
    
        Check the encoder wiring and that the encoder is firmly connected to the motor. Check the value of :code:`dump_errors(odrv0)` and then refer to the :ref:`error code documentation <error-codes>` for details.
        Once you understand the error and have fixed its cause, you may clear the error state with (:code:`odrv0.clear_errors()` :kbd:`Enter`) and retry.

    #. Start closed loop control by typing

        .. code:: iPython
            
            odrv0.axis0.requested_state = AXIS_STATE_CLOSED_LOOP_CONTROL
            
        and press :kbd:`Enter`. From now on the ODrive will try to hold the motor's position. If you try to turn it by hand, it will fight you gently. That is unless you bump up :code:`odrv0.axis0.motor.config.current_lim`, in which case it will fight you more fiercely. 
        If the motor begins to vibrate either immediately or after being disturbed you will need to :ref:`lower the controller gains <control-tuning>`.

    #. Send the motor a new position setpoint with 

        .. code:: iPython

            odrv0.axis0.controller.input_pos = 1
            
        The units are in turns.

    #. At this point you will probably want to :ref:`Properly tune <control-doc>` the motor controller in order to maximize system performance.

Other Control Modes
~~~~~~~~~~~~~~~~~~~~~~~~~~~~~~~~~~~~~~~~~~~~~~~~~~~~~~~~~~~~~~~~~~~~~~~~~~~~~~~~

The default control mode is unfiltered position control in the absolute encoder reference frame. 
The ODrive can be used with a variety of control modes, to learn more, check out the :ref:`control modes <control-modes-doc>` documentation page.

Watchdog Timer
--------------------------------------------------------------------------------

Each axis has a configurable watchdog timer that can stop the motors if the
control connection to the ODrive is interrupted.

Each axis has a configurable watchdog timeout: :code:`axis.config.watchdog_timeout`,
measured in seconds. Set 

.. code:: iPython
    
    axis.config.enable_watchdog = True
    
to turn on this feature.

The watchdog is fed using the :code:`axis.watchdog_feed()` method of each axis. 
Some :ref:`ascii commands <acsii-cmd-ref>` and most CANSimple commands feed the watchdog automatically.

What's next?
--------------------------------------------------------------------------------

You can now:
* :ref:`Properly tune <control-doc>` the motor controller to unlock the full potential of the ODrive.
* See what other :ref:`commands and parameters <commands-doc>` are available, in order to better control the ODrive.
* Control the ODrive from your own program or hook it up to an existing system through one of it's :ref:`interfaces <pinout-chart>`.
* See how you can improve the behavior during the startup procedure, like :ref:`bypassing encoder calibration <encoder-with-index-signal>`.
* The CAN communication is the most reliable way of talking to ODrive in a real application.  Check out the :ref:`CAN Guide <can-guide>` and :ref:`CAN Protocol <can-protocol>`

If you have any issues or any questions please get in touch. The `ODrive Community <https://discourse.odriverobotics.com/>`__ warmly welcomes you.

Upgrading from 0.4.12
--------------------------------------------------------------------------------

A new version (0.5.4) of ODrive firmware has released, complete with a new odrivetool. 
Follow the installation instructions, making sure to add the :code:`--upgrade` flag to pip commands, and check out the `Changelog <https://github.com/odriverobotics/ODrive/blob/master/CHANGELOG.md>`_ for changes!

The odrivetool will stage and restore your configuration.  
This probably isn't wise for the 0.4.12 -> 0.5.1 upgrade, so we suggest using :code:`odrv0.erase_configuration()` immediately after connecting the first time.

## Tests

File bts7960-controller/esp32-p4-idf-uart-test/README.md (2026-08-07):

# ESP32-P4 to STM32 UART diagnostic

This native ESP-IDF firmware is for ESP32-P4 revision 3.x boards that cannot
safely run the currently published generic MicroPython image.

## Wiring

Connect the ESP32-P4 GPIO21 and GPIO22 to STM32 PA9 and PA10 in either
orientation, plus a common ground. The firmware first listens on each ESP32
pin without enabling its TX output. After it finds the STM32 heartbeat, it uses
the other pin as TX and verifies the link with `PING` / `OK PONG`.

The diagnostic sends `MSTOP ALL` at connection time and never sends a motor
movement command.

## Build and flash

Use ESP-IDF 5.5.3 or newer for an ESP32-P4 revision 3.x chip:

```bash
idf.py set-target esp32p4
idf.py build
idf.py -p /dev/ttyACM0 flash
```

Do not flash a firmware image whose `esptool image-info` output has a maximum
chip revision below the revision reported by `esptool chip-id`.

## Terminal monitor

The board console is 115200 baud:

```bash
picocom -b 115200 /dev/ttyACM0
```

Exit picocom with `Ctrl-A`, then `Ctrl-X`.

Expected output includes:

```text
STM32 wiring detected: ESP32-P4 TX GPIO..., RX GPIO...
STM32: HB ...
UART ROUND TRIP VERIFIED: OK PONG
```

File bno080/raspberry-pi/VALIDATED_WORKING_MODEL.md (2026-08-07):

# Validated BNO080 UART-SHTP Model

## Validation record

This hardware/software arrangement was confirmed working on 2026-07-22:

- Raspberry Pi 5 running Raspberry Pi OS and regular Python 3 in Thonny.
- BNO080 configured for UART-SHTP mode.
- Pi UART4 exposed as `/dev/ttyAMA4` at the protocol's fixed 3,000,000 baud.
- Pi GPIO12 transmitted to the BNO080 RX input.
- Pi GPIO13 received from the BNO080 TX output.
- The standalone Python client completed an SHTP Buffer Status round trip.
- The BNO080 reported a 256-byte host-write buffer.
- The client enabled and received fused navigation reports.
- Fused heading, quaternion, calibrated magnetometer, gyroscope,
  accelerometer, and linear-acceleration values were displayed in Thonny.

Observed successful startup:

```text
BNO080 UART opened: /dev/ttyAMA4 at 3000000 baud (Pi TX GPIO12, RX GPIO13)
BNO080 UART-SHTP ROUND TRIP VERIFIED: buffer=256 bytes
BNO080 SHTP reset complete
BNO080 initialized; fused navigation reports received
BNO080 dynamic accel/gyro/magnetometer calibration started
```

The buffer-status response verifies bidirectional communication. Receiving
changing fused reports also verifies SHTP packet framing, SH-2 feature setup,
and sensor-report decoding.

## Validated wiring

| Raspberry Pi 5 | Physical pin | BNO080 | Function |
| --- | ---: | --- | --- |
| GPIO12 / UART4 TX | 32 | RX / SCL-RX | Commands to BNO080 |
| GPIO13 / UART4 RX | 33 | TX / SDA-TX | Reports to Pi |
| GND | Any Pi GND | GND | Common signal reference |

The sensor was selected for UART-SHTP mode before startup with `PS1=HIGH` and
`PS0=LOW`. UART logic is 3.3 V. Breakout-board power requirements still depend
on the exact module design and must not be inferred from this logic wiring.

## Pi configuration

`/boot/firmware/config.txt` contains this entry under `[all]`:

```ini
dtoverlay=uart4-pi5
```

The working Linux serial device is `/dev/ttyAMA4`. The client uses 3,000,000
baud, 8 data bits, no parity, and one stop bit as required by UART-SHTP.

## Working software

The validated client is [`bno080_uart.py`](bno080_uart.py). It runs in Thonny's
regular Python 3 interpreter and only depends on Raspberry Pi OS `pyserial`; it
does not require a virtual environment or the Adafruit BNO08X package.

Validated shell output was produced by:

```python
print_sample()
```

Dedicated magnetometer commands are also available:

```python
magnetometer()
print_magnetometer()
stream_magnetometer(5, 10)
```

## Not yet validated or calibrated

- Magnetometer calibration: the observed report accuracy was `0` (unreliable).
- Heading accuracy after calibration in the robot's final mounting position.
- Magnetic interference from motors, steel, and high-current wiring.
- Persistent saving and restoration of BNO080 calibration records.
- Raw accel/gyro/magnetometer report streaming on physical hardware.
- Long-duration operation and recovery after sensor or UART interruption.

These items must remain separate from the validated UART and fused-report path.

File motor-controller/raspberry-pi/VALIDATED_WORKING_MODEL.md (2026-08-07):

# Validated GD32 Stepper-Control Model

## Validation record

This hardware/software arrangement was confirmed working on 2026-07-22:

- Raspberry Pi 5 running normal Python 3 through Thonny.
- Creality Ender-3 v4.2.2 mainboard with a GD32F303RET6 MCU.
- Custom rover firmware on the Ender board, with heaters disabled and stepper
  motion controlled through newline-delimited Marlin commands.
- Direct 3.3 V, 115200-baud UART between the Pi and GD32 board.
- Raspberry Pi serial device `/dev/ttyAMA3` opened successfully.
- The GD32 heartbeat was received, acknowledged by the Pi, and confirmed by the
  `Ender UART round trip verified` message.
- The Thonny command `zmove(4000)` successfully moved the Z stepper output by
  4,000 driver microsteps.

The heartbeat acknowledgement verifies communication in both directions:

```text
GD32 PA9 TX -> Pi GPIO9 RX -> HB sequence received
GD32 PA10 RX <- Pi GPIO8 TX <- M118 HB_ACK sequence
GD32 PA9 TX -> Pi GPIO9 RX -> HB_ACK_OK confirmation
```

## Validated wiring

| Raspberry Pi 5 | Physical pin | Ender-3 v4.2.2 | Function |
|---|---:|---|---|
| GPIO8 / UART TX | 24 | GD32 PA10 / USART1 RX | Commands to GD32 |
| GPIO9 / UART RX | 21 | GD32 PA9 / USART1 TX | Replies and telemetry |
| GND | 20 or another Pi GND | Ender GND | Common signal reference |

The Pi and Ender board are powered normally and share UART ground. Their power
rails are not connected together.

The UART is tapped at the Ender board's CH340 nets. The CH340 TXD output must be
isolated from GD32 PA10 before Pi GPIO8 drives that receive net. A USB host must
not be connected to the Ender micro-USB port while using these direct UART taps.

## Working software

The validated Raspberry Pi client is
[`stepper_controller.py`](stepper_controller.py). It opens `/dev/ttyAMA3` at
115200 baud, 8N1 and starts a background receive thread. Run it with Thonny's
**Local Python 3** interpreter, not a MicroPython interpreter.

The working shell test was:

```python
zmove(4000)
```

The command uses the Z driver's default speed of 120 RPM. With the firmware's
configured 400 Z steps per logical unit, the client transmits a relative 10-unit
move and tracks the tagged completion response asynchronously.

The same client implements these host commands:

```python
xmove(signed_steps, rpm=None)
ymove(signed_steps, rpm=None)
zmove(signed_steps, rpm=None)
emove(signed_steps, rpm=None)
move(axis, signed_steps, rpm=None, wait=False, timeout=None)
move_sps(axis, signed_steps, steps_per_second)
set_speed(axis, rpm)
enable_drivers()
disable_drivers()
stop()
status()
switch_status()
```

## Larger robot integration

This model is intended to become one UART subsystem in the rover's later main
control process. The current module can be imported after its directory is on
Python's module search path:

```python
import stepper_controller as gd32

gd32.zmove(4000)
gd32.status()
```

Importing the module opens `/dev/ttyAMA3` and starts its daemon receive thread.
Only one process or module instance may own `/dev/ttyAMA3` at a time. The future
robot program should leave heartbeat processing in that thread and send complete
movement transactions through this API; it should not stream individual STEP
pulses from the Pi.

Each additional MCU must use its own Linux serial device and dedicated TX/RX
pair. Keep device names, baud rates, locks, receive workers, and protocol parsers
separate so one slow UART cannot block the others.

## Implemented but not yet physically validated here

The firmware and client implement the following, but this validation session did
not independently confirm each item on physical hardware:

- Pi-controlled motion on the X, Y, and E driver outputs.
- Positive and negative direction for every output.
- Per-command RPM and steps-per-second selection over the full configured range.
- A 200-revolution command under the rover's installed mechanical load.
- X/Y/Z switch telemetry and callback behavior on the Pi.
- Emergency `M410` stop behavior during loaded motion.
- Long-duration operation, electrical-noise immunity, and driver temperatures.

These items should be added to this record only after hardware testing. Driver
current remains controlled by the board's VREF potentiometers, and all four
driver enable inputs remain physically shared.

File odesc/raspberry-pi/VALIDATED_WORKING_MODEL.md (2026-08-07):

# Validated ODESC UART Model

## Validation record

This hardware/software arrangement was confirmed working on 2026-07-22:

- Raspberry Pi 5 running Raspberry Pi OS and regular Python 3 in Thonny.
- ODESC identified over USB as `1209:0d32 Generic ODrive Robotics ODrive v3`.
- Pi UART2 exposed as `/dev/ttyAMA2` at 115200 baud, 8N1.
- Pi GPIO4 transmitted to ODESC GPIO2/UART RX.
- Pi GPIO5 received from ODESC GPIO1/UART TX.
- The ODESC responded to multiple ODrive ASCII protocol property reads.
- `config.enable_uart` returned `1` and `config.uart_baudrate` returned `115200`.
- Axis1 reported idle state `1` and axis error `0d` (decimal zero).

Observed successful values:

```text
ODESC UART IS WORKING
Bus voltage: 35.653049 V
config.enable_uart: 1
config.uart_baudrate: 115200
axis1.current_state: 1
axis1.error: 0d
```

Each value was returned in response to a command sent by the Pi. This verifies
Pi TX, ODESC RX and command parsing, ODESC TX, and Pi RX. Merely opening the
Linux serial device would not verify those paths.

## Validated wiring

| Raspberry Pi 5 | Physical pin | ODESC | Function |
| --- | ---: | --- | --- |
| GPIO4 / UART2 TX | 7 | GPIO2 / UART RX | ASCII commands to ODESC |
| GPIO5 / UART2 RX | 29 | GPIO1 / UART TX | Replies from ODESC |
| GND | Any Pi GND | GND | Common signal reference |

UART is 3.3 V logic. The ODESC was separately powered and reported a 35.653049 V
DC bus during validation. The Pi must not power the ODESC motor bus.

## Pi and ODESC configuration

The Pi configuration uses:

```ini
dtoverlay=uart2-pi5
```

The corresponding port is `/dev/ttyAMA2`. Do not substitute a UART4 overlay
while using GPIO4/GPIO5. The ODESC's saved configuration was checked over its
USB CDC interface before the Pi test and already contained:

```text
config.enable_uart = 1
config.uart_baudrate = 115200
```

No ODESC configuration change was required.

## Working software

The reusable validated client is [`odesc_uart.py`](odesc_uart.py). Running the
file directly executes non-motion property reads and prints raw TX/RX bytes.
Importing it provides `ODESCUART` for later integration into the rover API.

## Not yet validated

- Physical ODESC motor movement from the new Raspberry Pi velocity controls.
- Axis1 sensorless startup and operation in the rover drivetrain.
- Controller-level watchdog behavior after complete Pi power/process loss.
- Software and independent hardware emergency stops.
- Long-duration operation near motor wiring and immunity to electrical noise.
- Recovery following an ODESC reboot, USB connection, or UART disconnection.

These items must not be treated as working merely because the UART property
read round trip is validated.

## 2026-07-24 diagnostic extension

The deployed web service successfully read live extended telemetry without
moving either motor:

```text
vbus_voltage approximately 34.18 V
ibus 0.0 A
bus power 0.0 W
axis0 state 1, all errors 0
axis1 state 1, all errors 0
axis0 motor pre-calibrated true, encoder pre-calibrated false
axis1 motor pre-calibrated false, encoder pre-calibrated false
```

Both axes reported velocity-control mode `2`, passthrough input mode `1`, a
10 A current limit, and a 15 turns/s velocity limit. The missing encoder
calibration explains why the former state-8 encoder velocity path was not
appropriate, but the clone also exposes the older state-5 sensorless path.

Additional read-only properties established:

```text
firmware 0.0.0 unreleased (custom clone build)
axis0 motor pre-calibrated true
axis0 sensorless ramp 4 A, approximately 5.00 mechanical turns/s
axis0 sensorless acceleration approximately 1.82 turns/s^2
axis0 pole pairs 7, PM flux linkage 0.004633 Wb
axis1 motor pre-calibrated false
```

`axis*.config.enable_sensorless_mode` is absent, while legacy
`axis*.config.startup_sensorless_control` and requested state `5` are present.
The driver and web server therefore use the legacy state-5 open-loop startup
ramp, enforce its minimum running speed, reject live direction reversal, and
stop by requesting IDLE. Axis 1 is blocked until deliberate motor-only
calibration.

The deployed web service was validated with no motor movement:

- all four UART links remained connected after deployment;
- axis 0 and axis 1 remained in IDLE with all reported faults zero;
- a read-only ODESC status press was persisted as a successful event;
- an intentionally wrong arm phrase was rejected and persisted as an error;
- the service remained active with `NRestarts=0`.

Physical motor movement remains outside this validated record until a
raised-mechanism test is performed with an independent power disconnect ready.

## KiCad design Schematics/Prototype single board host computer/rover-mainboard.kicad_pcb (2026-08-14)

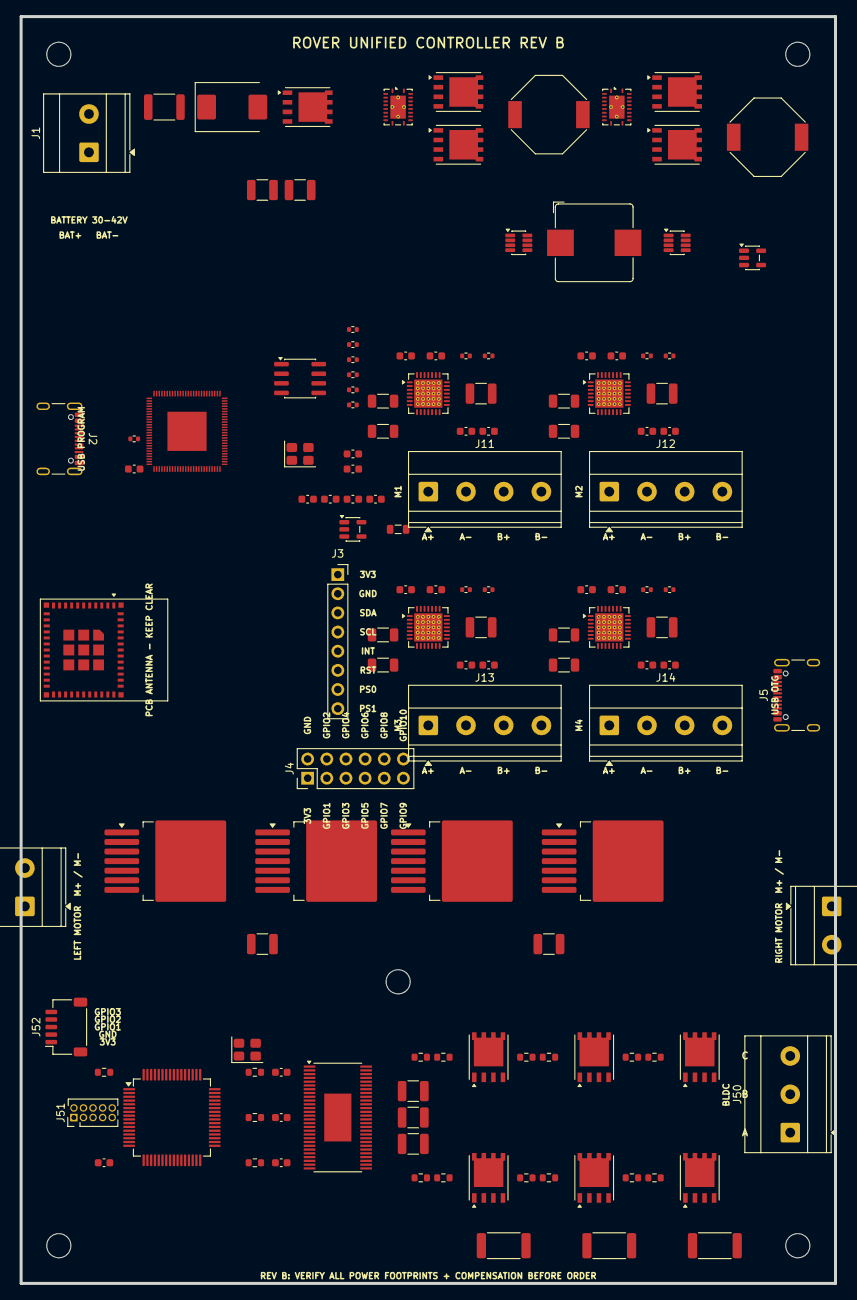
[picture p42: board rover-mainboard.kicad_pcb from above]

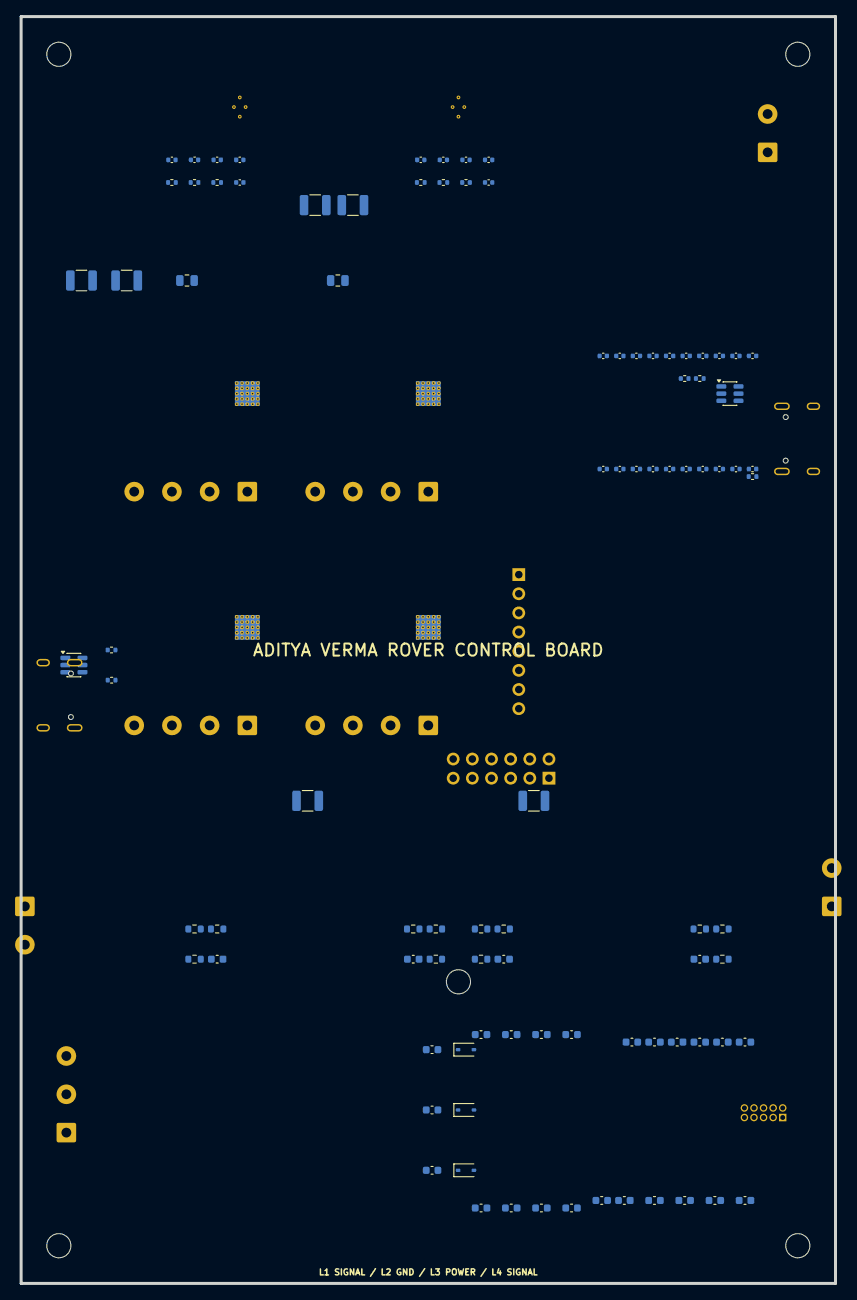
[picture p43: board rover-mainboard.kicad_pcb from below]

Board: 4 copper layers, 108.0 x 168.0 mm, 230 parts (93 on the bottom side), 10 nets, no tracks yet.

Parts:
C1B, C2B, C3B, C4B: 100uF 35V BULK; C_1210_3225Metric
C1C, C2C, C3C, C4C: 100nF VDD; C_0603_1608Metric
C1D, C2D, C3D, C4D, C326: 1uF VREG; C_0603_1608Metric
C1E, C2E, C3E, C4E: 100nF CP1-CP2; C_0603_1608Metric
C1F, C2F, C3F, C4F: 100nF VCP; C_0603_1608Metric
C40, C41: 2.2uF 100V INPUT; C_1210_3225Metric
C42, C43: 22uF 35V 24VOUT; C_1210_3225Metric
C44, C45: 47uF 16V 8VOUT; C_1210_3225Metric
C46: 22uF 10V 5VOUT; C_0805_2012Metric
C47: 22uF 6V3 3V3OUT; C_0805_2012Metric
C100, C101, C102, C103, C104, C105, C106, C107, C108, C109, C110, C111, C112, C113, C114, C115, C116, C117, C118, C119: 100nF P4 DECOUPLING; C_0402_1005Metric
C120: 10uF VDD_LDO; C_0603_1608Metric
C121: 10uF VDD_DCDCC; C_0603_1608Metric
C122: 4.7uF USBPHY; C_0603_1608Metric
C123: 1uF FLASHIO; C_0603_1608Metric
C124: 10nF USBPHY; C_0603_1608Metric
C125: 10uF VDD_BAT; C_0603_1608Metric
C126: 1uF CHIP_PU; C_0603_1608Metric
C200, C208: 100nF VCC; C_0402_1005Metric
C201, C209: 100nF BST; C_0402_1005Metric
C202, C210: 1uF SS; C_0402_1005Metric
C203, C211: 1nF COMP; C_0402_1005Metric
C204, C212: 100pF COMP; C_0402_1005Metric
C300, C320: 470nF BTN SUPPLY; C_1210_3225Metric
C300#2, C301#2, C302#2, C303#2, C304, C305: 100nF; C_0603_1608Metric
C301, C321: 220uF 16V DRIVE BULK; C_1210_3225Metric
C302, C303, C322#2, C323#2: 1nF IS FILTER; C_0603_1608Metric
C306, C307: 2.2uF VCAP; C_0603_1608Metric
C308: 4.7uF VDDA; C_0603_1608Metric
C309: 100nF VDDA; C_0603_1608Metric
C310, C311: 18pF XTAL; C_0603_1608Metric
C312: 100nF NRST; C_0603_1608Metric
C320#2: 1uF GVDD; C_0603_1608Metric
C321#2: 100nF DVDD; C_0603_1608Metric
C322: 2.2uF AVDD; C_0603_1608Metric
C323, C327: 10uF PVDD; C_0603_1608Metric
C324: 10nF CP1; C_0603_1608Metric
C325: 100nF CP2; C_0603_1608Metric
C331, C332, C333: 100nF BOOTSTRAP; C_0603_1608Metric
C340, C341, C342: 120uF 50V BLDC BUS; C_1210_3225Metric
CCS51, CCS52, CCS53: 1nF CURRENT SENSE; C_0603_1608Metric
D1: SMCJ48A TVS; D_SMC
D10: USB FS ESD ARRAY; SOT-23-6
D11: USB HS LOW-C ESD; SOT-23-6
D51, D52, D53: 60V BOOTSTRAP; D_SOD-323
F1: 15A INPUT FUSE; Fuse_1812_4532Metric
H1, H2, H3, H4, H5: M3; MountingHole_3.2mm_M3
J1: 10S BATTERY; TerminalBlock_Phoenix_MKDS-3-2-5.08_1x02_P5.08mm_Horizontal
J2: USB-C PROGRAM/DEBUG; USB_C_Receptacle_GCT_USB4105-xx-A_16P_TopMnt_Horizontal
J3: BNO080 BREAKOUT; PinSocket_1x08_P2.54mm_Vertical
J4: OPEN GPIO; PinHeader_2x06_P2.54mm_Vertical
J5: USB-C OTG HIGH SPEED; USB_C_Receptacle_GCT_USB4105-xx-A_16P_TopMnt_Horizontal
J11: STEPPER 1: A+ A- B+ B-; TerminalBlock_Phoenix_MKDS-1,5-4_1x04_P5.00mm_Horizontal
J12: STEPPER 2: A+ A- B+ B-; TerminalBlock_Phoenix_MKDS-1,5-4_1x04_P5.00mm_Horizontal
J13: STEPPER 3: A+ A- B+ B-; TerminalBlock_Phoenix_MKDS-1,5-4_1x04_P5.00mm_Horizontal
J14: STEPPER 4: A+ A- B+ B-; TerminalBlock_Phoenix_MKDS-1,5-4_1x04_P5.00mm_Horizontal
J30: LEFT MOTOR; TerminalBlock_Phoenix_MKDS-3-2-5.08_1x02_P5.08mm_Horizontal
J32: RIGHT MOTOR; TerminalBlock_Phoenix_MKDS-3-2-5.08_1x02_P5.08mm_Horizontal
J50: BLDC U V W; TerminalBlock_Phoenix_MKDS-3-3-5.08_1x03_P5.08mm_Horizontal
J51: STM32 SWD; PinHeader_2x05_P1.27mm_Vertical
J52: ODESC AUX 3V3 GND IO1 IO2 IO3; JST_SH_SM05B-SRSS-TB_1x05-1MP_P1.00mm_Horizontal
L13: 2.2uH P4 CORE; L_0805_2012Metric
L40: 10uH 24V; L_Bourns-SRU1028_10.0x10.0mm
L41: 6.8uH 8V; L_Bourns-SRU1028_10.0x10.0mm
L42: 4.7uH 5V; L_Bourns_SRP1038C_10.0x10.0mm
Q1: 80V REVERSE-POLARITY FET; PowerPAK_SO-8_Single
Q40, Q41: NVMFS6B14NLT1G 100V BUCK; PowerPAK_SO-8_Single
Q42, Q43, Q50, Q51, Q52, Q53, Q54, Q55: NTMFS5C628NLT1G 60V MOSFET; PowerPAK_SO-8_Single
R1A, R1B, R2A, R2B, R3A, R3B, R4A, R4B: 0.10R SENSE; R_1206_3216Metric
R1C, R2C, R3C, R4C: 100k ENABLE PD; R_0402_1005Metric
R1D, R2D, R3D, R4D: 100k STEP PD; R_0402_1005Metric
R30A, R30C, R32A, R32C: 10k IN PD; R_0603_1608Metric
R30B, R30D, R32B, R32D: 10k INH PD; R_0603_1608Metric
R30E, R30F, R32E, R32F: 1k IS FILTER; R_0603_1608Metric
R100: 10k CHIP_PU; R_0402_1005Metric
R101: 10k BOOT; R_0402_1005Metric
R102, R103, R104, R105, R106, R107: 0R FLASH TUNING; R_0402_1005Metric
R110, R111, R112, R113: 22R USB SERIES; R_0402_1005Metric
R205, R213: 10k FB; R_0402_1005Metric
R206: 287k FB24; R_0402_1005Metric
R207, R215: 10R GATE; R_0402_1005Metric
R214: 90.9k FB8; R_0402_1005Metric
R300: 10k NRST; R_0603_1608Metric
RCS51, RCS52, RCS53: 20R CURRENT SENSE; R_0603_1608Metric
RG51, RG52, RG53, RG54, RG55, RG56: 2.2R GATE; R_0603_1608Metric
RPD51, RPD52, RPD53, RPD54, RPD55, RPD56: 100k GATE PD; R_0603_1608Metric
RSH50, RSH51, RSH52: 0.5mR 3W; R_2512_6332Metric
U10: ESP32-P4NRW32X QFN104
U11: W25Q128JVSIQ; SOIC-8_3.9x4.9mm_P1.27mm
U12: ESP32-C6-MINI-1-H4 PCB ANTENNA; ESP32-C6-MINI-1
U13: TLV62569 P4 CORE DCDC; SOT-23-5
U21: A4988SETTR-T AXIS1; QFN-28-1EP_5x5mm_P0.5mm_EP3.75x3.75mm_ThermalVias
U22: A4988SETTR-T AXIS2; QFN-28-1EP_5x5mm_P0.5mm_EP3.75x3.75mm_ThermalVias
U23: A4988SETTR-T AXIS3; QFN-28-1EP_5x5mm_P0.5mm_EP3.75x3.75mm_ThermalVias
U24: A4988SETTR-T AXIS4; QFN-28-1EP_5x5mm_P0.5mm_EP3.75x3.75mm_ThermalVias
U30: BTN7960B LEFT HALF-A; TO-263-7_TabPin4
U31: BTN7960B LEFT HALF-B; TO-263-7_TabPin4
U32: BTN7960B RIGHT HALF-A; TO-263-7_TabPin4
U33: BTN7960B RIGHT HALF-B; TO-263-7_TabPin4
U40: LM5146 42V->24V; Texas_RGY_R-PVQFN-N20_EP2.05x3.05mm_ThermalVias
U41: LM5146 24V->8V; Texas_RGY_R-PVQFN-N20_EP2.05x3.05mm_ThermalVias
U42: MP2315 8V->5V 3A; TSOT-23-8
U43: MP2315 5V->3V3 3A; TSOT-23-8
U44: AP2112 3V3 SENSOR LDO; SOT-23-5
U50: STM32F405RGT6; LQFP-64_10x10mm_P0.5mm
U51: DRV8301DCAR; HTSSOP-56-1EP_6.1x14mm_P0.5mm_EP3.61x6.35mm
Y1: 40MHz; Crystal_SMD_3225-4Pin_3.2x2.5mm
Y50: 8MHz STM32; Crystal_SMD_3225-4Pin_3.2x2.5mm

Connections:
+3V3_LOGIC: J4.1, J52.1, U21.18, U22.18, U23.18, U24.18
+5V_LOGIC: J2.A4, J2.A9, J2.B4, J2.B9, J5.A4, J5.A9, J5.B4, J5.B9, U21.17, U22.17, U23.17, U24.17
+8V_DRIVE: U30.5, U31.5, U32.5, U33.5
+24V_STEPPER: U21.10, U22.10, U23.10, U24.10
GND: D1.2, J1.2, J2.A1, J2.A12, J2.B1, J2.B12, J3.2, J4.2, J5.A1, J5.A12, J5.B1, J5.B12, J52.2, U21.8, U21.9, U21.29, U22.8, U22.9, U22.29, U23.8, U23.9, U23.29, U24.8, U24.9, U24.29, U30.1, U31.1, U32.1, U33.1
J2_USB_DM: J2.A7, J2.B7
J2_USB_DP: J2.A6, J2.B6
J5_USB_DM: J5.A7, J5.B7
J5_USB_DP: J5.A6, J5.B6
VBAT_10S_30_42V: D1.1, F1.1, F1.2, J1.1

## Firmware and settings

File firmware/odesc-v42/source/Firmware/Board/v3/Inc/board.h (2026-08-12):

/*
* @brief Contains board specific configuration for ODrive v3.x
*/

#ifndef __BOARD_CONFIG_H
#define __BOARD_CONFIG_H

#include <stdbool.h>

// STM specific includes
#include <stm32f4xx_hal.h>
#include <gpio.h>
#include <spi.h>
#include <tim.h>
#include <can.h>
#include <i2c.h>
#include <usb_device.h>
#include <main.h>
#include "cmsis_os.h"

#include <arm_math.h>

#include <Drivers/STM32/stm32_system.h>

#if HW_VERSION_MINOR <= 3
#define SHUNT_RESISTANCE (675e-6f)
#else
#define SHUNT_RESISTANCE (500e-6f)
#endif

#define AXIS_COUNT (2)

// Total count of GPIOs, including encoder pins, CAN pins and a dummy GPIO0.
// ODrive v3.4 and earlier don't have GPIOs 6, 7 and 8 but to keep the numbering
// consistent we just leave a gap in the counting scheme.
#define GPIO_COUNT  (17)

#define CAN_FREQ (2000000UL)

#if HW_VERSION_MINOR >= 5 && HW_VERSION_VOLTAGE >= 48
#define DEFAULT_BRAKE_RESISTANCE (2.0f) // [ohm]
#else
#define DEFAULT_BRAKE_RESISTANCE (0.47f) // [ohm]
#endif

#define DEFAULT_ERROR_PIN 0
#define DEFAULT_MIN_DC_VOLTAGE 8.0f

#define DEFAULT_GPIO_MODES \
    ODriveIntf::GPIO_MODE_DIGITAL, \
    ODriveIntf::GPIO_MODE_UART_A, \
    ODriveIntf::GPIO_MODE_UART_A, \
    ODriveIntf::GPIO_MODE_ANALOG_IN, \
    ODriveIntf::GPIO_MODE_ANALOG_IN, \
    ODriveIntf::GPIO_MODE_ANALOG_IN, \
    ODriveIntf::GPIO_MODE_DIGITAL, \
    ODriveIntf::GPIO_MODE_DIGITAL, \
    ODriveIntf::GPIO_MODE_DIGITAL, \
    ODriveIntf::GPIO_MODE_ENC0, \
    ODriveIntf::GPIO_MODE_ENC0, \
    ODriveIntf::GPIO_MODE_DIGITAL_PULL_DOWN, \
    ODriveIntf::GPIO_MODE_ENC1, \
    ODriveIntf::GPIO_MODE_ENC1, \
    ODriveIntf::GPIO_MODE_DIGITAL_PULL_DOWN, \
    ODriveIntf::GPIO_MODE_CAN_A, \
    ODriveIntf::GPIO_MODE_CAN_A,

#define TIM_TIME_BASE TIM14

// Run control loop at the same frequency as the current measurements.
#define CONTROL_TIMER_PERIOD_TICKS  (2 * TIM_1_8_PERIOD_CLOCKS * (TIM_1_8_RCR + 1))

#define TIM1_INIT_COUNT (TIM_1_8_PERIOD_CLOCKS / 2 - 1 * 128) // TODO: explain why this offset

// The delta from the control loop timestamp to the current sense timestamp is
// exactly 0 for M0 and TIM1_INIT_COUNT for M1.
#define MAX_CONTROL_LOOP_UPDATE_TO_CURRENT_UPDATE_DELTA (TIM_1_8_PERIOD_CLOCKS / 2 + 1 * 128)

#ifdef __cplusplus
#include <Drivers/DRV8301/drv8301.hpp>
#include <Drivers/STM32/stm32_gpio.hpp>
#include <Drivers/STM32/stm32_spi_arbiter.hpp>
#include <MotorControl/pwm_input.hpp>
#include <MotorControl/thermistor.hpp>

using TGateDriver = Drv8301;
using TOpAmp = Drv8301;

#include <MotorControl/motor.hpp>
#include <MotorControl/encoder.hpp>

extern std::array<Axis, AXIS_COUNT> axes;
extern Motor motors[AXIS_COUNT];
extern OnboardThermistorCurrentLimiter fet_thermistors[AXIS_COUNT];
extern Encoder encoders[AXIS_COUNT];
extern Stm32Gpio gpios[GPIO_COUNT];

struct GpioFunction { int mode = 0; uint8_t alternate_function = 0xff; };
extern std::array<GpioFunction, 3> alternate_functions[GPIO_COUNT];

extern USBD_HandleTypeDef& usb_dev_handle;

extern Stm32SpiArbiter& ext_spi_arbiter;

extern UART_HandleTypeDef* uart_a;
extern UART_HandleTypeDef* uart_b;
extern UART_HandleTypeDef* uart_c;

extern PwmInput pwm0_input;
#endif

// Period in [s]
#define CURRENT_MEAS_PERIOD ( (float)2*TIM_1_8_PERIOD_CLOCKS*(TIM_1_8_RCR+1) / (float)TIM_1_8_CLOCK_HZ )
static const float current_meas_period = CURRENT_MEAS_PERIOD;

// Frequency in [Hz]
#define CURRENT_MEAS_HZ ( (float)(TIM_1_8_CLOCK_HZ) / (float)(2*TIM_1_8_PERIOD_CLOCKS*(TIM_1_8_RCR+1)) )
static const int current_meas_hz = CURRENT_MEAS_HZ;

#if HW_VERSION_VOLTAGE >= 48
// Flipsky/SEQURE ODESC V4.2 56V uses the 11:1 voltage-sense divider.
#define VBUS_S_DIVIDER_RATIO 11.0f
#elif HW_VERSION_VOLTAGE == 24
#define VBUS_S_DIVIDER_RATIO 11.0f
#else
#error "unknown board voltage"
#endif

// Linear range of the DRV8301 opamp output: 0.3V...5.7V. We set the upper limit
// to 3.0V so that it's symmetric around the center point of 1.65V.
#define CURRENT_SENSE_MIN_VOLT  0.3f
#define CURRENT_SENSE_MAX_VOLT  3.0f

// This board has no board-specific user configurations
static inline bool board_read_config() { return true; }
static inline bool board_write_config() { return true; }
static inline void board_clear_config() { }
static inline bool board_apply_config() { return true; }

void system_init();
bool board_init();
void start_timers();

#if ODESC_ADC_DIAGNOSTIC
// All bits must remain set while the read-only ADC diagnostic is running.
#define ODESC_DIAGNOSTIC_SAFE_STATUS_ALL ((1UL << 12) - 1UL)
void diagnostic_configure_safe_pins();
void diagnostic_force_safe_outputs();
uint32_t diagnostic_safety_status();
extern volatile uint32_t diagnostic_safety_fault_count;
#endif

#endif // __BOARD_CONFIG_H

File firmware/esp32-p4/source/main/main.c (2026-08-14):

#include <stdbool.h>
#include <stdint.h>
#include <stdio.h>
#include <stdlib.h>
#include <string.h>

#include "driver/gpio.h"
#include "driver/uart.h"
#include "esp_http_server.h"
#include "esp_log.h"
#include "esp_timer.h"
#include "freertos/FreeRTOS.h"
#include "freertos/semphr.h"
#include "freertos/task.h"
#include "network_ota.h"
#include "nvs_flash.h"
#include "odesc_link.h"
#include "rover_link.h"
#include "speaker.h"
#include "battery_history.h"
#include "mower_history.h"
#include "bno080_link.h"
#include "stepper_link.h"
#include "drive_control.h"

#define STM32_UART UART_NUM_1
#define STM32_BAUD 115200
#define STM32_TX_GPIO 21
#define STM32_RX_GPIO 22
#define UART_RX_PROBE_MS 2400
#define UART_REPLY_MS 700
#define UART_LINK_TIMEOUT_MS 3500
#define MOTOR_LEASE_MS 800
#define STATUS_INTERVAL_MS 450
#define LINE_CAPACITY 192
#define TANK_DEFAULT_RAMP_PERCENT 80
#define TANK_TARGET_TIMEOUT_MS 450
#define TANK_UPDATE_MS 50
#define DRIVE_BUS_VOLTAGE 8.0f
#define BTS7960_SENSE_AMPS_PER_VOLT 8.5f

static const char *TAG = "robot_ap";

typedef struct {
    char direction;
    unsigned duty;
    unsigned current_a_raw;
    unsigned current_b_raw;
    unsigned current_a_mv;
    unsigned current_b_mv;
} motor_state_t;

typedef struct {
    bool alive;
    int tx_gpio;
    int rx_gpio;
    int64_t last_rx_ms;
    unsigned heartbeat_ms;
    motor_state_t motors[2];
    unsigned encoders[4];
    unsigned encoder_sequence;
    unsigned encoder_rate_hz;
    unsigned watchdog;
    char last_reply[128];
    char last_error[128];
} robot_state_t;

static robot_state_t state = {
    .tx_gpio = -1,
    .rx_gpio = -1,
    .motors = {{.direction = 'S'}, {.direction = 'S'}},
};
static SemaphoreHandle_t state_mutex;
static SemaphoreHandle_t uart_mutex;
static bool uart_installed;
static char uart_line_buffer[LINE_CAPACITY];
static size_t uart_line_length;
static int64_t motor_lease_deadline_ms;
static int tank_target[2];
static int tank_output[2];
static unsigned tank_ramp_percent = TANK_DEFAULT_RAMP_PERCENT;
static int64_t tank_target_deadline_ms;
static int64_t tank_last_update_ms;
static int64_t tank_last_send_ms;
static bool tank_mode_active;
static bool motor_stop_pending;
static bool imu_calibration_owns_drive;
static bool autonomous_sequence_owns_drive;
static bool autonomous_sequence_started_encoders;

static int64_t now_ms(void)
{
    return esp_timer_get_time() / 1000;
}

static esp_err_t send_conflict(httpd_req_t *request, const char *message)
{
    httpd_resp_set_status(request, "409 Conflict");
    httpd_resp_set_type(request, "text/plain");
    return httpd_resp_sendstr(request, message);
}

static void state_error(const char *message)
{
    xSemaphoreTake(state_mutex, portMAX_DELAY);
    snprintf(state.last_error, sizeof(state.last_error), "%s", message);
    xSemaphoreGive(state_mutex);
}

static void state_reply(const char *line)
{
    xSemaphoreTake(state_mutex, portMAX_DELAY);
    snprintf(state.last_reply, sizeof(state.last_reply), "%s", line);
    if (strncmp(line, "ERR ", 4) == 0 || strncmp(line, "FAULT ", 6) == 0) {
        snprintf(state.last_error, sizeof(state.last_error), "%s", line);
    } else {
        state.last_error[0] = '\0';
    }
    xSemaphoreGive(state_mutex);
}

static void process_stm32_line(const char *line)
{
    ESP_LOGI(TAG, "STM32: %s", line);

    xSemaphoreTake(state_mutex, portMAX_DELAY);
    state.last_rx_ms = now_ms();

    if (strncmp(line, "HB ", 3) == 0) {
        state.heartbeat_ms = (unsigned)strtoul(line + 3, NULL, 10);
        state.alive = state.tx_gpio >= 0 && state.rx_gpio >= 0;
    } else if (strncmp(line, "READY ", 6) == 0 || strcmp(line, "OK PONG") == 0) {
        state.alive = state.tx_gpio >= 0 && state.rx_gpio >= 0;
        snprintf(state.last_reply, sizeof(state.last_reply), "%s", line);
    } else if (strncmp(line, "MSTAT ", 6) == 0) {
        char d1 = 'S';
        char d2 = 'S';
        unsigned motor1 = 0;
        unsigned motor2 = 0;
        unsigned wd = 0;
        motor_state_t m1 = {0};
        motor_state_t m2 = {0};
        const int fields = sscanf(
            line,
            "MSTAT %u %c %u %u %u %u %u %u %c %u %u %u %u %u WD %u",
            &motor1, &d1, &m1.duty, &m1.current_a_raw, &m1.current_b_raw,
            &m1.current_a_mv, &m1.current_b_mv, &motor2, &d2, &m2.duty,
            &m2.current_a_raw, &m2.current_b_raw, &m2.current_a_mv,
            &m2.current_b_mv, &wd);
        if (fields == 15 && motor1 == 1 && motor2 == 2) {
            m1.direction = d1;
            m2.direction = d2;
            state.motors[0] = m1;
            state.motors[1] = m2;
            state.watchdog = wd;
            snprintf(state.last_reply, sizeof(state.last_reply), "%s", line);
        } else {
            snprintf(state.last_error, sizeof(state.last_error),
                     "Malformed MSTAT (%d fields)", fields);
        }
    } else if (strncmp(line, "ENC ", 4) == 0) {
        unsigned stm32_ms = 0;
        unsigned values[4];
        if (sscanf(line, "ENC %u %u %u %u %u %u", &state.encoder_sequence,
                   &stm32_ms, &values[0], &values[1], &values[2], &values[3]) == 6) {
            memcpy(state.encoders, values, sizeof(values));
        } else {
            snprintf(state.last_error, sizeof(state.last_error), "Malformed ENC");
        }
    } else {
        snprintf(state.last_reply, sizeof(state.last_reply), "%s", line);
        if (strncmp(line, "ERR ", 4) == 0 || strncmp(line, "FAULT ", 6) == 0) {
            snprintf(state.last_error, sizeof(state.last_error), "%s", line);
        }
    }
    xSemaphoreGive(state_mutex);
}

static bool uart_read_line(char *output, size_t output_size, uint32_t timeout_ms)
{
    const int64_t deadline = now_ms() + timeout_ms;
    uint8_t byte;

    while (now_ms() < deadline) {
        int remaining = (int)(deadline - now_ms());
        TickType_t wait = pdMS_TO_TICKS(remaining > 20 ? 20 : remaining);
        if (uart_read_bytes(STM32_UART, &byte, 1, wait) != 1) {
            continue;
        }
        if (byte == '\n') {
            if (uart_line_length == 0) {
                continue;
            }
            uart_line_buffer[uart_line_length] = '\0';
            snprintf(output, output_size, "%s", uart_line_buffer);
            uart_line_length = 0;
            return true;
        }
        if (byte == '\r') {
            continue;
        }
        if (uart_line_length < sizeof(uart_line_buffer) - 1) {
            uart_line_buffer[uart_line_length++] = (char)byte;
        } else {
            uart_line_length = 0;
        }
    }
    return false;
}

static void uart_close(void)
{
    if (uart_installed) {
        uart_driver_delete(STM32_UART);
        uart_installed = false;
    }
    gpio_reset_pin(STM32_TX_GPIO);
    gpio_reset_pin(STM32_RX_GPIO);
    uart_line_length = 0;
}

static bool uart_open_probe(int rx_gpio)
{
    uart_close();
    const uart_config_t config = {
        .baud_rate = STM32_BAUD,
        .data_bits = UART_DATA_8_BITS,
        .parity = UART_PARITY_DISABLE,
        .stop_bits = UART_STOP_BITS_1,
        .flow_ctrl = UART_HW_FLOWCTRL_DISABLE,
        .rx_flow_ctrl_thresh = 0,
        .source_clk = UART_SCLK_DEFAULT,
    };
    if (uart_driver_install(STM32_UART, 1024, 0, 0, NULL, 0) != ESP_OK) {
        return false;
    }
    uart_installed = true;
    if (uart_param_config(STM32_UART, &config) != ESP_OK ||
        uart_set_pin(STM32_UART, UART_PIN_NO_CHANGE, rx_gpio,
                     UART_PIN_NO_CHANGE, UART_PIN_NO_CHANGE) != ESP_OK) {
        uart_close();
        return false;
    }
    gpio_set_pull_mode(rx_gpio, GPIO_PULLUP_ONLY);
    uart_flush_input(STM32_UART);
    return true;
}

static bool uart_probe_rx(int rx_gpio)
{
    char line[LINE_CAPACITY];
    ESP_LOGI(TAG, "Probing STM32 TX on ESP32-P4 GPIO%d", rx_gpio);
    if (!uart_open_probe(rx_gpio)) {
        return false;
    }
    int64_t deadline = now_ms() + UART_RX_PROBE_MS;
    while (now_ms() < deadline) {
        if (!uart_read_line(line, sizeof(line), 100)) {
            continue;
        }
        process_stm32_line(line);
        if (strncmp(line, "HB ", 3) == 0 || strncmp(line, "READY ", 6) == 0) {
            return true;
        }
    }
    return false;
}

static void uart_send(const char *command)
{
    uart_write_bytes(STM32_UART, command, strlen(command));
    uart_write_bytes(STM32_UART, "\n", 1);
    uart_wait_tx_done(STM32_UART, pdMS_TO_TICKS(100));
    ESP_LOGI(TAG, "TX: %s", command);
}

static bool uart_command_locked(const char *command, const char *expected,
                                uint32_t timeout_ms)
{
    char line[LINE_CAPACITY];
    if (!uart_installed) {
        return false;
    }
    uart_send(command);
    int64_t deadline = now_ms() + timeout_ms;
    while (now_ms() < deadline) {
        if (!uart_read_line(line, sizeof(line), 80)) {
            continue;
        }
        process_stm32_line(line);
        if (expected == NULL || strncmp(line, expected, strlen(expected)) == 0) {
            state_reply(line);
            return true;
        }
        if (strncmp(line, "ERR ", 4) == 0) {
            state_reply(line);
            return false;
        }
    }
    char error[96];
    snprintf(error, sizeof(error), "No STM32 reply to %s", command);
    state_error(error);
    return false;
}

static bool uart_command(const char *command, const char *expected,
                         uint32_t timeout_ms)
{
    bool result;
    if (xSemaphoreTake(uart_mutex, pdMS_TO_TICKS(timeout_ms + 300)) != pdTRUE) {
        state_error("STM32 UART busy");
        return false;
    }
    result = uart_command_locked(command, expected, timeout_ms);
    xSemaphoreGive(uart_mutex);
    return result;
}

static bool uart_find_link(void)
{
    char line[LINE_CAPACITY];

    xSemaphoreTake(uart_mutex, portMAX_DELAY);
    if (uart_probe_rx(STM32_RX_GPIO) &&
        uart_set_pin(STM32_UART, STM32_TX_GPIO, STM32_RX_GPIO,
                     UART_PIN_NO_CHANGE, UART_PIN_NO_CHANGE) == ESP_OK) {
        uart_send("MSTOP ALL");
        uart_send("PING");
        int64_t deadline = now_ms() + 1200;
        while (now_ms() < deadline) {
            if (!uart_read_line(line, sizeof(line), 100)) continue;
            process_stm32_line(line);
            if (strcmp(line, "OK PONG") != 0) continue;
            xSemaphoreTake(state_mutex, portMAX_DELAY);
            state.alive = true;
            state.tx_gpio = STM32_TX_GPIO;
            state.rx_gpio = STM32_RX_GPIO;
            state.last_rx_ms = now_ms();
            xSemaphoreGive(state_mutex);
            ESP_LOGI(TAG, "STM32 fixed UART verified: TX GPIO%d RX GPIO%d",
                     STM32_TX_GPIO, STM32_RX_GPIO);
            xSemaphoreGive(uart_mutex);
            return true;
        }
    }
    uart_close();
    xSemaphoreTake(state_mutex, portMAX_DELAY);
    state.alive = false;
    state.tx_gpio = -1;
    state.rx_gpio = -1;
    xSemaphoreGive(state_mutex);
    xSemaphoreGive(uart_mutex);
    return false;
}

static void set_tank_target(int left, int right, unsigned ramp_percent,
                            bool immediate_stop)
{
    if (left > 4095) left = 4095;
    if (left < -4095) left = -4095;
    if (right > 4095) right = 4095;
    if (right < -4095) right = -4095;
    if (ramp_percent < 10) ramp_percent = 10;
    if (ramp_percent > 300) ramp_percent = 300;

    xSemaphoreTake(state_mutex, portMAX_DELAY);
    if (!tank_mode_active) {
        tank_last_update_ms = now_ms();
        tank_last_send_ms = 0;
    }
    tank_target[0] = left;
    tank_target[1] = right;
    tank_ramp_percent = ramp_percent;
    tank_target_deadline_ms = now_ms() + TANK_TARGET_TIMEOUT_MS;
    tank_mode_active = true;
    if (immediate_stop) {
        tank_target[0] = tank_target[1] = 0;
        tank_output[0] = tank_output[1] = 0;
        tank_mode_active = false;
        tank_target_deadline_ms = 0;
        motor_lease_deadline_ms = 0;
        motor_stop_pending = true;
    }
    xSemaphoreGive(state_mutex);
}

static void set_controller_targets(int left, int right, unsigned ramp_percent,
                                   bool immediate_stop, int16_t x_rpm,
                                   int16_t y_rpm, int16_t z_rpm)
{
    static bool controller_stepper_active;
    xSemaphoreTake(state_mutex, portMAX_DELAY);
    bool imu_owns_drive = imu_calibration_owns_drive;
    bool autonomous_owns_drive = autonomous_sequence_owns_drive;
    xSemaphoreGive(state_mutex);
    if (imu_owns_drive || autonomous_owns_drive) {
        if (immediate_stop) {
            bno080_link_abort_calibration();
            set_tank_target(0, 0, 300, true);
        }
        return;
    }
    set_tank_target(left, right, ramp_percent, immediate_stop);
    if (immediate_stop) {
        if (controller_stepper_active) stepper_link_quick_stop();
        controller_stepper_active = false;
        return;
    }
    if (stepper_link_set_direct_rpm(x_rpm, y_rpm, z_rpm, 400)) {
        controller_stepper_active = true;
    } else {
        ESP_LOGD(TAG, "Controller stepper command ignored until GD32 direct link is ready");
    }
}

static bool imu_motion_begin(void)
{
    rover_link_status_t controller = {0};
    rover_link_get_status(&controller);
    xSemaphoreTake(state_mutex, portMAX_DELAY);
    bool allowed = state.alive && !controller.active && !imu_calibration_owns_drive;
    if (allowed) imu_calibration_owns_drive = true;
    xSemaphoreGive(state_mutex);
    if (allowed) set_tank_target(0, 0, 300, true);
    return allowed;
}

static bool imu_motion_drive(int left, int right, unsigned ramp_percent,
                             bool immediate_stop)
{
    xSemaphoreTake(state_mutex, portMAX_DELAY);
    bool owns_drive = imu_calibration_owns_drive && state.alive;
    xSemaphoreGive(state_mutex);
    if (owns_drive) set_tank_target(left, right, ramp_percent, immediate_stop);
    return owns_drive;
}

static void imu_motion_end(void)
{
    set_tank_target(0, 0, 300, true);
    xSemaphoreTake(state_mutex, portMAX_DELAY);
    imu_calibration_owns_drive = false;
    xSemaphoreGive(state_mutex);
}

bool drive_control_autonomous_begin(void)
{
    rover_link_status_t controller = {0};
    rover_link_get_status(&controller);
    xSemaphoreTake(state_mutex, portMAX_DELAY);
    bool allowed = state.alive && !controller.active &&
                   !imu_calibration_owns_drive &&
                   !autonomous_sequence_owns_drive;
    bool encoders_running = state.encoder_rate_hz != 0;
    if (allowed) autonomous_sequence_owns_drive = true;
    xSemaphoreGive(state_mutex);
    if (!allowed) return false;

    set_tank_target(0, 0, 300, true);
    if (!encoders_running &&
        uart_command("ENCON 50", "OK ENCON", UART_REPLY_MS)) {
        xSemaphoreTake(state_mutex, portMAX_DELAY);
        state.encoder_rate_hz = 50;
        autonomous_sequence_started_encoders = true;
        xSemaphoreGive(state_mutex);
    } else if (!encoders_running) {
        xSemaphoreTake(state_mutex, portMAX_DELAY);
        autonomous_sequence_owns_drive = false;
        xSemaphoreGive(state_mutex);
        return false;
    }
    return true;
}

bool drive_control_autonomous_set_percent(int left_percent, int right_percent)
{
    if (left_percent < -100 || left_percent > 100 ||
        right_percent < -100 || right_percent > 100) return false;
    xSemaphoreTake(state_mutex, portMAX_DELAY);
    bool owns_drive = autonomous_sequence_owns_drive && state.alive;
    xSemaphoreGive(state_mutex);
    if (!owns_drive) return false;
    set_tank_target(left_percent * 4095 / 100,
                    right_percent * 4095 / 100, 200, false);
    return true;
}

bool drive_control_autonomous_get_encoders(uint16_t adc[4], uint32_t *sequence)
{
    if (!adc) return false;
    xSemaphoreTake(state_mutex, portMAX_DELAY);
    bool valid = autonomous_sequence_owns_drive && state.alive &&
                 state.encoder_rate_hz != 0;
    for (int i = 0; i < 4; ++i) adc[i] = (uint16_t)state.encoders[i];
    if (sequence) *sequence = state.encoder_sequence;
    xSemaphoreGive(state_mutex);
    return valid;
}

void drive_control_autonomous_end(void)
{
    set_tank_target(0, 0, 300, true);
    xSemaphoreTake(state_mutex, portMAX_DELAY);
    bool stop_encoders = autonomous_sequence_started_encoders;
    autonomous_sequence_started_encoders = false;
    autonomous_sequence_owns_drive = false;
    xSemaphoreGive(state_mutex);
    if (stop_encoders && uart_command("ENCOFF", "OK ENCOFF", UART_REPLY_MS)) {
        xSemaphoreTake(state_mutex, portMAX_DELAY);
        state.encoder_rate_hz = 0;
        xSemaphoreGive(state_mutex);
    }
}

static int ramp_value(int current, int target, int step)
{
    if ((current < 0 && target > 0) || (current > 0 && target < 0)) target = 0;
    if (current < target) return current + step > target ? target : current + step;
    if (current > target) return current - step < target ? target : current - step;
    return current;
}

static bool send_track_output(int motor, int signed_duty)
{
    if (signed_duty == 0) {
        char command[20];
        snprintf(command, sizeof(command), "MSTOP %d", motor);
        return uart_command(command, "OK MSTOP", UART_REPLY_MS);
    }
    // Both installed tracks use BTS7960 direction B for rover-forward.
    char direction = signed_duty > 0 ? 'B' : 'A';
    unsigned duty = (unsigned)(signed_duty > 0 ? signed_duty : -signed_duty);
    char command[40];
    snprintf(command, sizeof(command), "MOTOR %d %c %u", motor, direction, duty);
    return uart_command(command, "OK MOTOR", UART_REPLY_MS);
}

static void service_tank_ramp(void)
{
    int next[2] = {0};
    int previous[2] = {0};
    bool stop_now = false;
    bool refresh_outputs = false;
    int64_t now = now_ms();

    xSemaphoreTake(state_mutex, portMAX_DELAY);
    if (motor_stop_pending) {
        motor_stop_pending = false;
        stop_now = true;
    } else if (tank_mode_active && now >= tank_target_deadline_ms) {
        tank_target[0] = tank_target[1] = 0;
        tank_output[0] = tank_output[1] = 0;
        tank_mode_active = false;
        tank_target_deadline_ms = 0;
        motor_lease_deadline_ms = 0;
        stop_now = true;
    } else if (tank_mode_active && now - tank_last_update_ms >= TANK_UPDATE_MS) {
        int elapsed = tank_last_update_ms ? (int)(now - tank_last_update_ms) : TANK_UPDATE_MS;
        if (elapsed > 200) elapsed = 200;
        int step = (4095 * (int)tank_ramp_percent * elapsed) / 100000;
        if (step < 1) step = 1;
        tank_last_update_ms = now;
        for (int i = 0; i < 2; ++i) {
            previous[i] = tank_output[i];
            tank_output[i] = ramp_value(tank_output[i], tank_target[i], step);
            next[i] = tank_output[i];
        }
        motor_lease_deadline_ms = now + MOTOR_LEASE_MS;
        refresh_outputs = now - tank_last_send_ms >= 250;
        if (refresh_outputs) tank_last_send_ms = now;
    }
    xSemaphoreGive(state_mutex);

    if (stop_now) {
        uart_command("MSTOP ALL", "OK MSTOP ALL", UART_REPLY_MS);
        return;
    }
    for (int i = 0; i < 2; ++i) {
        // tank_output[0] is the physical left track (Motor 2); slot 1 is right (Motor 1).
        const int motor = i == 0 ? 2 : 1;
        if (next[i] != previous[i] || refresh_outputs) send_track_output(motor, next[i]);
    }
}
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
void app_main(void)
{
    esp_err_t result = nvs_flash_init();
    if (result == ESP_ERR_NVS_NO_FREE_PAGES || result == ESP_ERR_NVS_NEW_VERSION_FOUND) {
        ESP_ERROR_CHECK(nvs_flash_erase());
        result = nvs_flash_init();
    }
    ESP_ERROR_CHECK(result);

    state_mutex = xSemaphoreCreateMutex();
    uart_mutex = xSemaphoreCreateMutex();
    ESP_ERROR_CHECK(state_mutex && uart_mutex ? ESP_OK : ESP_ERR_NO_MEM);

    xTaskCreate(uart_service_task, "stm32_uart", 6144, NULL, 8, NULL);
    ESP_ERROR_CHECK(stepper_link_start());
    ESP_ERROR_CHECK(odesc_link_start());
    ESP_ERROR_CHECK(network_ota_start());
    result = speaker_start();
    if (result != ESP_OK) {
        ESP_LOGE(TAG, "Speaker unavailable: %s", esp_err_to_name(result));
    }
    result = battery_history_start();
    if (result != ESP_OK) {
        ESP_LOGE(TAG, "Battery history unavailable: %s", esp_err_to_name(result));
    }
    result = mower_history_start();
    if (result != ESP_OK) {
        ESP_LOGE(TAG, "Mower history unavailable: %s", esp_err_to_name(result));
    }
    result = bno080_link_start(imu_motion_begin, imu_motion_drive, imu_motion_end);
    if (result != ESP_OK) {
        ESP_LOGE(TAG, "BNO080 unavailable: %s", esp_err_to_name(result));
    }
    ESP_ERROR_CHECK(rover_link_start(set_controller_targets));
    ESP_ERROR_CHECK(start_web_server() ? ESP_OK : ESP_FAIL);
    network_ota_mark_running_app_valid();
}

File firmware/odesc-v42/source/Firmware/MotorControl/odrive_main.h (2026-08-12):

#ifndef __ODRIVE_MAIN_H
#define __ODRIVE_MAIN_H

// Hardware configuration
#include <board.h>

#ifdef __cplusplus
#include <communication/interface_usb.h>
#include <communication/interface_i2c.h>
#include <communication/interface_uart.h>
#include <task_timer.hpp>
extern "C" {
#endif

// OS includes
#include <cmsis_os.h>

// extern const float elec_rad_per_enc;
extern uint32_t _reboot_cookie;

extern uint64_t serial_number;
extern char serial_number_str[13];

#ifdef __cplusplus
}

typedef struct {
    bool fully_booted;
    uint32_t uptime; // [ms]
    uint32_t min_heap_space; // FreeRTOS heap [Bytes]
    uint32_t max_stack_usage_axis; // minimum remaining space since startup [Bytes]
    uint32_t max_stack_usage_usb;
    uint32_t max_stack_usage_uart;
    uint32_t max_stack_usage_startup;
    uint32_t max_stack_usage_can;
    uint32_t max_stack_usage_analog;

    uint32_t stack_size_axis;
    uint32_t stack_size_usb;
    uint32_t stack_size_uart;
    uint32_t stack_size_startup;
    uint32_t stack_size_can;
    uint32_t stack_size_analog;

    int32_t prio_axis;
    int32_t prio_usb;
    int32_t prio_uart;
    int32_t prio_startup;
    int32_t prio_can;
    int32_t prio_analog;

    USBStats_t& usb = usb_stats_;
    I2CStats_t& i2c = i2c_stats_;
} SystemStats_t;

struct PWMMapping_t {
    endpoint_ref_t endpoint = {0, 0};
    float min = 0;
    float max = 0;
};

// @brief general user configurable board configuration
struct BoardConfig_t {
    ODriveIntf::GpioMode gpio_modes[GPIO_COUNT] = {
        DEFAULT_GPIO_MODES
    };

    bool enable_uart_a = true;
    bool enable_uart_b = false;
    bool enable_uart_c = false;
    uint32_t uart_a_baudrate = 115200;
    uint32_t uart_b_baudrate = 115200;
    uint32_t uart_c_baudrate = 115200;
    bool enable_can_a = true;
    bool enable_i2c_a = false;
    ODriveIntf::StreamProtocolType uart0_protocol = ODriveIntf::STREAM_PROTOCOL_TYPE_ASCII_AND_STDOUT;
    ODriveIntf::StreamProtocolType uart1_protocol = ODriveIntf::STREAM_PROTOCOL_TYPE_ASCII_AND_STDOUT;
    ODriveIntf::StreamProtocolType uart2_protocol = ODriveIntf::STREAM_PROTOCOL_TYPE_ASCII_AND_STDOUT;
    ODriveIntf::StreamProtocolType usb_cdc_protocol = ODriveIntf::STREAM_PROTOCOL_TYPE_ASCII_AND_STDOUT;
    float max_regen_current = 0.0f;
    float brake_resistance = DEFAULT_BRAKE_RESISTANCE;
    bool enable_brake_resistor = false;
    float dc_bus_undervoltage_trip_level = DEFAULT_MIN_DC_VOLTAGE;      //<! [V] minimum voltage below which the motor stops operating
    float dc_bus_overvoltage_trip_level = 1.07f * HW_VERSION_VOLTAGE;   //<! [V] maximum voltage above which the motor stops operating.
                                                                        //<! This protects against cases in which the power supply fails to dissipate
                                                                        //<! the brake power if the brake resistor is disabled.
                                                                        //<! The default is 26V for the 24V board version and 52V for the 48V board version.

    /**
     * If enabled, if the measured DC voltage exceeds `dc_bus_overvoltage_ramp_start`,
     * the ODrive will sink more power than usual into the the brake resistor
     * in an attempt to bring the voltage down again.
     * 
     * The brake duty cycle is increased by the following amount:
     *  vbus_voltage == dc_bus_overvoltage_ramp_start  =>  brake_duty_cycle += 0%
     *  vbus_voltage == dc_bus_overvoltage_ramp_end  =>  brake_duty_cycle += 100%
     * 
     * Remarks:
     *  - This feature is active even when all motors are disarmed.
     *  - This feature is disabled if `brake_resistance` is non-positive.
     */
    bool enable_dc_bus_overvoltage_ramp = false;
    float dc_bus_overvoltage_ramp_start = 1.07f * HW_VERSION_VOLTAGE; //!< See `enable_dc_bus_overvoltage_ramp`.
                                                                      //!< Do not set this lower than your usual vbus_voltage,
                                                                      //!< unless you like fried brake resistors.
    float dc_bus_overvoltage_ramp_end = 1.07f * HW_VERSION_VOLTAGE; //!< See `enable_dc_bus_overvoltage_ramp`.
                                                                    //!< Must be larger than `dc_bus_overvoltage_ramp_start`,
                                                                    //!< otherwise the ramp feature is disabled.

    float dc_max_positive_current = INFINITY; // Max current [A] the power supply can source
    float dc_max_negative_current = -0.01f; // Max current [A] the power supply can sink. You most likely want a non-positive value here. Set to -INFINITY to disable.
    uint32_t error_gpio_pin = DEFAULT_ERROR_PIN;
    PWMMapping_t pwm_mappings[4];
    PWMMapping_t analog_mappings[GPIO_COUNT];
};
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

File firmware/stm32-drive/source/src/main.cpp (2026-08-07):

#include <Arduino.h>
#include <ctype.h>
#include <stdio.h>
#include <stdlib.h>
#include <string.h>

// Host UART:
//   STM32 PA9 TX  -> Raspberry Pi GPIO1 RX
//   STM32 PA10 RX <- Raspberry Pi GPIO0 TX
static HardwareSerial HostUart(PA_10, PA_9);

static const uint32_t UART_BAUD = 115200;
static const uint32_t HEARTBEAT_MS = 1000;
static const uint32_t HOST_WATCHDOG_MS = 1500;
static const uint32_t UART_LED_TIMEOUT_MS = 2500;
static const uint32_t UART_LED_TOGGLE_MS = 250;
static const uint32_t PWM_HZ = 20000;
static const uint32_t TIMER_CLOCK_HZ = 72000000;
static const uint16_t PWM_PERIOD_COUNTS = TIMER_CLOCK_HZ / PWM_HZ;
static const uint16_t PWM_MAX_DUTY = 4095;
static const uint16_t ADC_MAX_RAW = 4095;
static const uint16_t ADC_REF_MV = 3300;
static const uint8_t ADC_SAMPLES = 16;
static const uint8_t ENCODER_ADC_SAMPLES = 4;
static const uint16_t DEFAULT_ENCODER_HZ = 50;
static const uint16_t DIRECTION_DEADTIME_US = 20;
static const uint8_t MAX_UART_BYTES_PER_LOOP = 64;
static const int ENCODER_TX_RESERVE = 48;

static const uint32_t encoderPins[] = {PA0, PA1, PA2, PA3};
static const size_t ENCODER_COUNT = sizeof(encoderPins) / sizeof(encoderPins[0]);

struct MotorConfig {
  const char *name;
  uint32_t pwmA;
  uint32_t pwmB;
  uint32_t currentA;
  uint32_t currentB;
  volatile uint32_t *compareA;
  volatile uint32_t *compareB;
};

struct MotorState {
  char direction;
  uint16_t duty;
};
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

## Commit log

2026-10-14 Add RTK board and XIAO Sense to BOM
2026-10-14 Set current prices for added BOM items
2026-10-14 Fix camera and GPS assembly instructions
2026-10-14 Add CAD assembly image to README
2026-10-14 Remove colon from CAD assembly heading
2026-10-14 Remove RTK board from README BOM
2026-10-14 Add XIAO camera firmware and flashing guide
2026-10-14 Add GPS module to README BOM
